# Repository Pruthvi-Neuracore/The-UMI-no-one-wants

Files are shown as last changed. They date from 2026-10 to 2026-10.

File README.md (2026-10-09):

# The UMI no one wants

<p align="center">
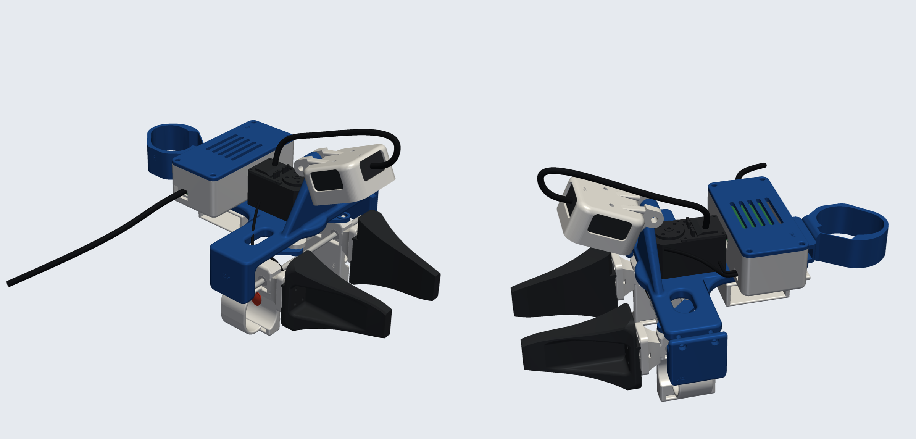
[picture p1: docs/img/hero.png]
The UMI no one wants: hand-worn gripper with an Intel RealSense D405 wrist camera
  
</p>

A hand-worn gripper for collecting bimanual manipulation data without a robot in the loop. It has an
**Intel RealSense D405** depth camera on the wrist, an on-board **IMU and Raspberry Pi Pico 2**, a **record button** under
your index finger, and a single USB cable to your laptop.

- **Depth wrist camera:** the D405 sits in a cup on a stiff Ø12 / M4 hinge at the end of a braced camera post that flares
  out of the frame; triangulated gussets tie both hinge lugs into the cup. It looks forward and down at the fingers (65° below horizontal, about 9–10 cm away; the D405's minimum
  range is 7 cm). The camera cable leaves from the top window and runs back into the electronics box.
- **Finger sleeves:** each finger link has a sleeve that wraps the finger, so the fingers stay in place while you open and
  close the gripper.
- **Record button:** a 6 × 6 mm tactile switch sits in the inner wall of the index-finger sleeve under a soft, domed
  TPU pad where your finger pad rests. Press it with your index finger, once to start recording and again to stop. It's wired to the Pico.
- **One cable:** a closed electronics box holds a USB 3 hub, the Pico 2 and the IMU. The camera and the Pico both connect to
  the hub, and one USB-C cable goes to the laptop. See [docs/electronics.md](docs/electronics.md).
- **Universal tip flange:** each finger link has a 20 × 30 mm flange with M2 (8 × 12), M3 (12 × 24 + centre pair) and M4
  (12 mm pair) hole patterns, so you can bolt on tips that match different robot grippers.
- **Moulded look:** every printed part is softly rounded: a blended T-plate outline, rounded slot rims, a concave blend into
  the end wall; the end cover and electronics box match.
- **Small PG mark:** every printed part has a small PG logo engraved 0.2 mm deep on one visible face, as a subtle
  maker's mark. The gripper tips stay plain.
- **Checked in a full assembly:** the gripper is clash-checked closed, half-open and fully open with every tip set.

## Record button

<p align="center">
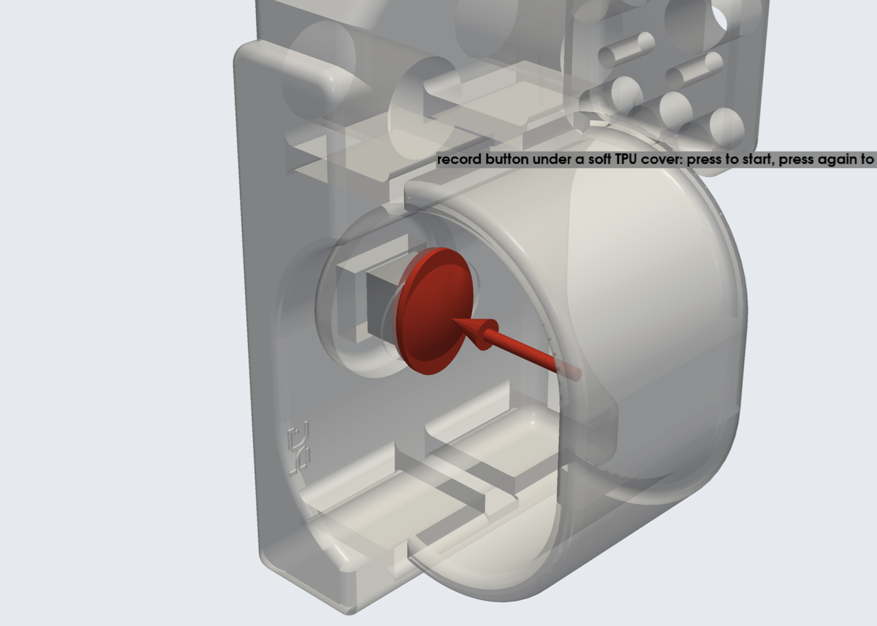
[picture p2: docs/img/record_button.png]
Record button at the front of the index-finger sleeve
  
</p>

A 6 × 6 mm tactile switch is set into the inner wall of the index-finger sleeve, where the finger pad rests, under a soft
TPU cover: a 12 × 9 mm oval pad with a gentle 0.8 mm dome and rounded rim, so nothing sharp touches your finger, and a nub
underneath that presses the switch. The cover sits in a matching oval recess, and a rounded boss on the outside of the paddle
gives the switch its depth. A cavity behind the switch leaves room for its legs and solder joints and opens at the back
for soldering. Press it with your index finger: **press once to start recording, press again to stop.** It's wired to the Pico (GP15 to ground,
internal pull-up), so the recording software only has to watch one input; see [docs/electronics.md](docs/electronics.md).
That wall is also the one your finger pushes to close the gripper, so use a stiff switch (about 250–320 gf); the
software can tell a deliberate press from a grasp by its duration. The wires leave through the back of the paddle and
run along the frame to the electronics box with a little slack for the finger link's travel.

## Tips for different robots

Swap the tips to match the robot you'll deploy on, so the jaws on the device have the same shape as the robot's fingers.

| Tips on the device | Robot |
|---|---|
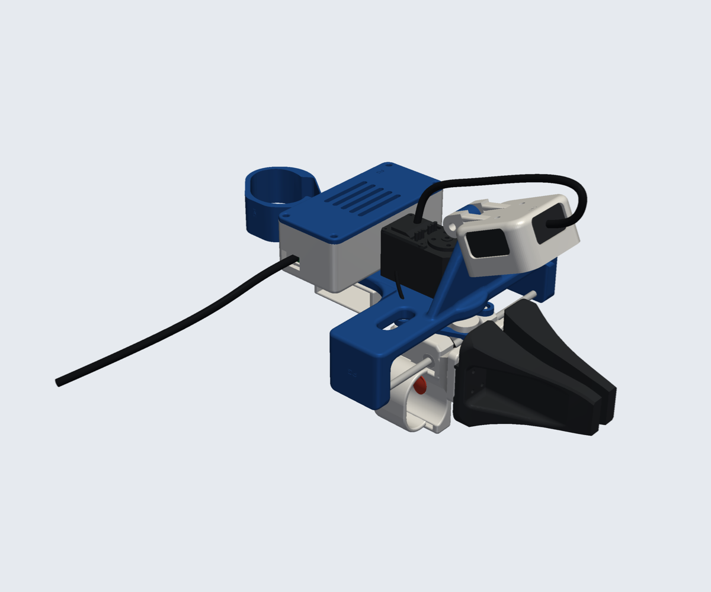
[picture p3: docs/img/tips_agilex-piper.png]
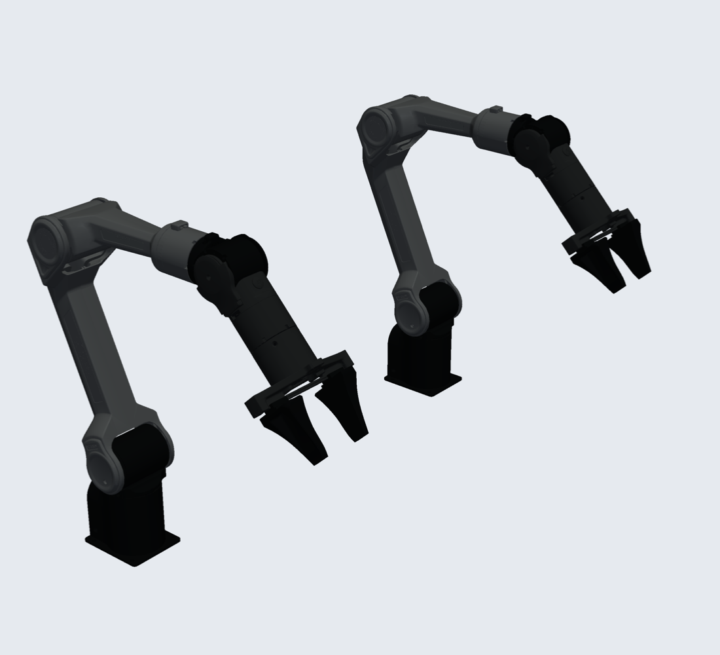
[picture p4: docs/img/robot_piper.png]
|  **AgileX Piper tips** |  **AgileX Piper** |
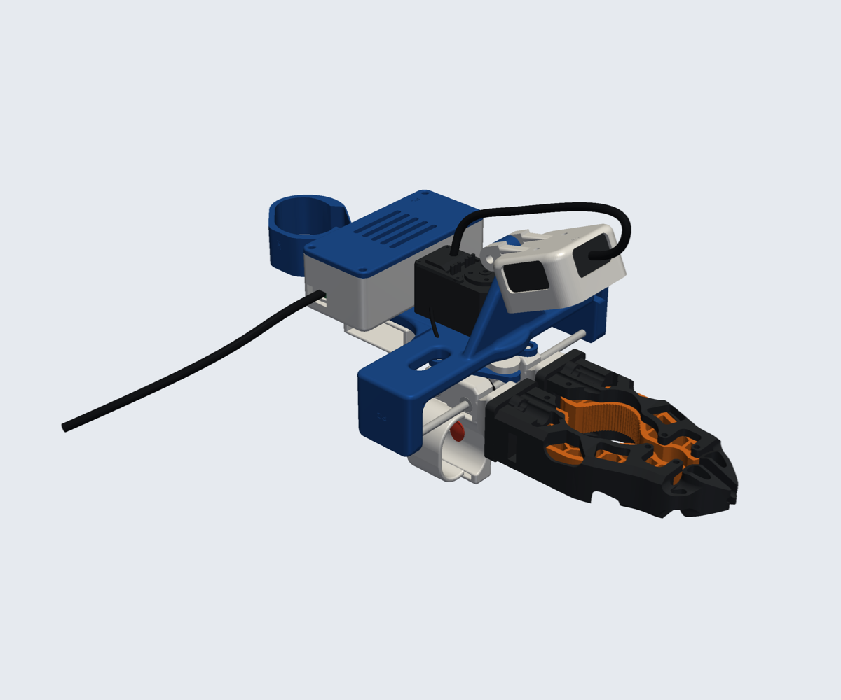
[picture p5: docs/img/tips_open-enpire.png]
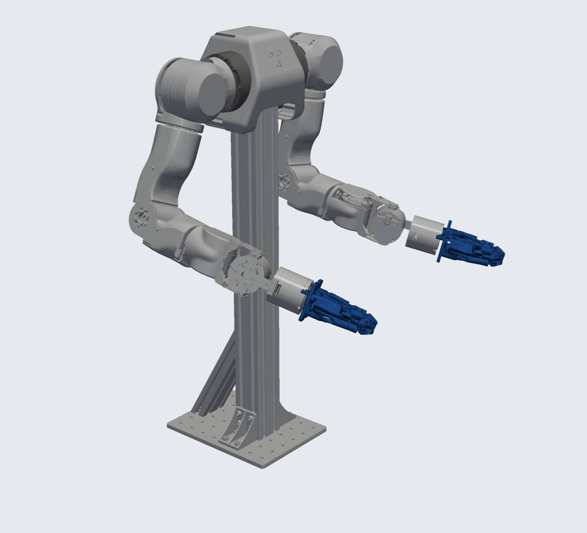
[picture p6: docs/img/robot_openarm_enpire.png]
|  **Open-ENPIRE compliant fingers** |  **OpenArm with Open-ENPIRE fingers** |
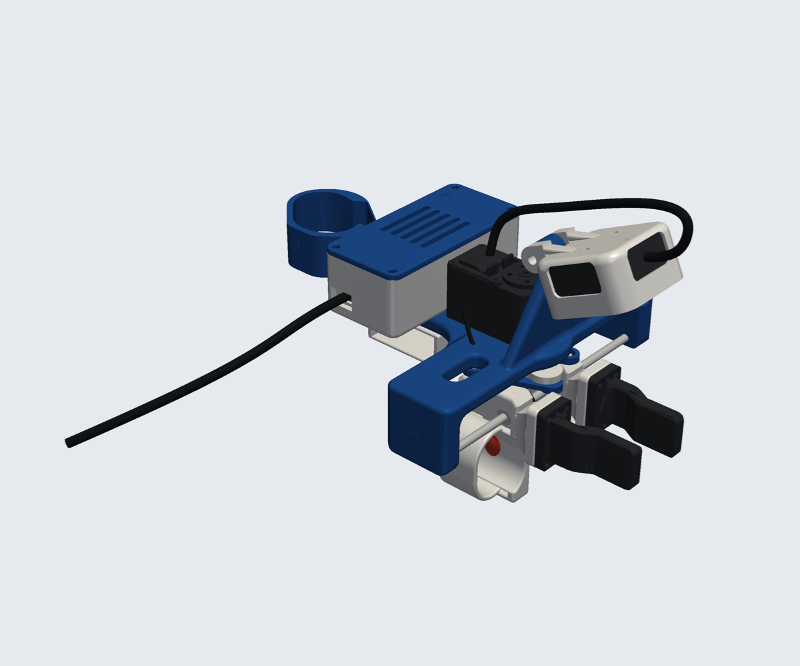
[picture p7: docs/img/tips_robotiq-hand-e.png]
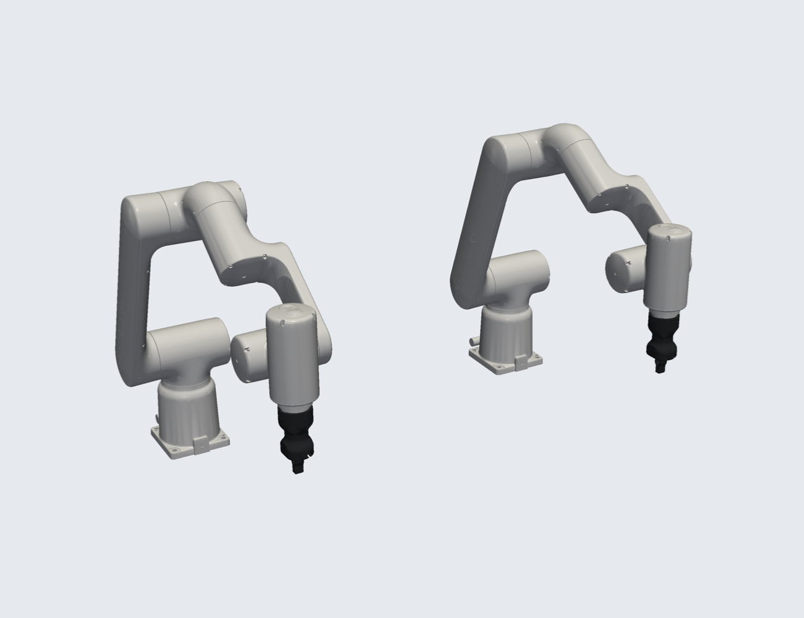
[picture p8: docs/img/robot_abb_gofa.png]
|  **Robotiq Hand-E fingers** |  **ABB GoFa CRB 15000 (dual) with Hand-E** |
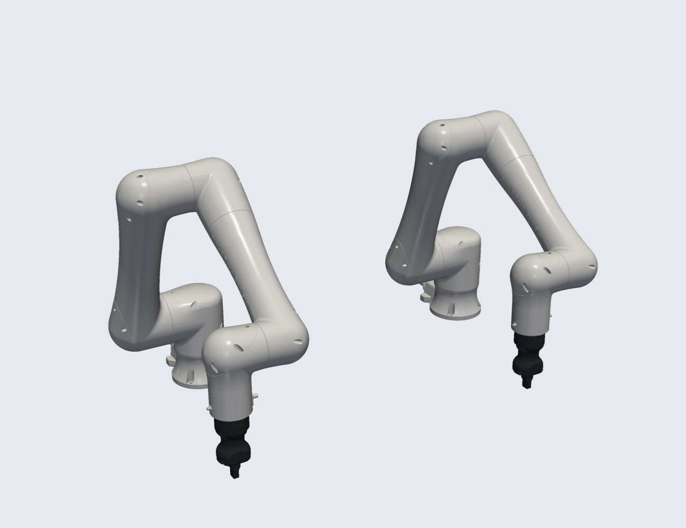
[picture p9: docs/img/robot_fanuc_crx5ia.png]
|  **Robotiq Hand-E fingers** |  **FANUC CRX-5iA (dual) with Hand-E** |
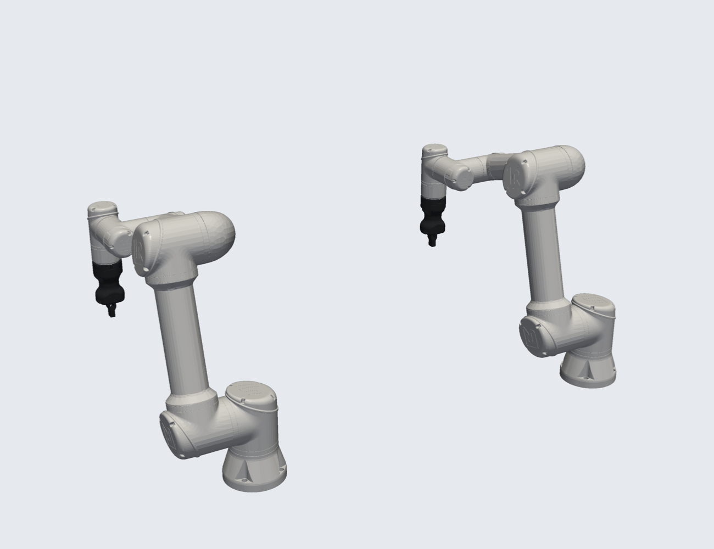
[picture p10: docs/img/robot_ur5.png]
|  **Robotiq Hand-E fingers** |  **UR5 (dual) with Hand-E** |

- **Piper tips** (`hardware/STL/gripper_tips/AgileX-Piper/`): the AgileX Piper jaw and pad, shown on the device above.
- **Open-ENPIRE tips, for OpenArm** (`hardware/STL/gripper_tips/Open-ENPIRE/`): the compliant finger from
  [Open-ENPIRE-Gripper](https://github.com/pgeedh/Open-ENPIRE-Gripper) with its robot mount replaced by a flange plate
 . The matching OpenArm finger is in `Open-ENPIRE/robot/OpenArm_Hard.stl` (mm), so the same finger
  shape is on the device and on the robot. The ENPIRE fingers are about 32 mm thick, so the jaws meet a little before
  the mechanism's own stop.
- **Hand-E tips, for ABB, FANUC and UR** (`hardware/STL/gripper_tips/Robotiq-Hand-E/`): the actual Robotiq Hand-E finger
  on a flange plate. Print it twice; the index jaw is the same part turned 180°, so the stepped
  fingertips face each other.

Robot renders are made from the robots' published descriptions (sources in
[`hardware/NOTICE.md`](hardware/NOTICE.md)).

## Assembly

The full assembled device (right hand, half open) is in [`assembly/`](assembly/), once per tip set:

| File | Use |
|---|---|
| `umi_right_agilex-piper.glb`, `umi_right_open-enpire.glb`, `umi_right_robotiq-hand-e.glb` | Coloured, one node per part, metres, Y up; drag into Onshape, Blender or any glTF viewer |
| `umi_right_agilex-piper.stl`, `umi_right_open-enpire.stl`, `umi_right_robotiq-hand-e.stl` | One merged mesh in mm, Z up |

The left hand is the mirror image.

## Parts

<p align="center">
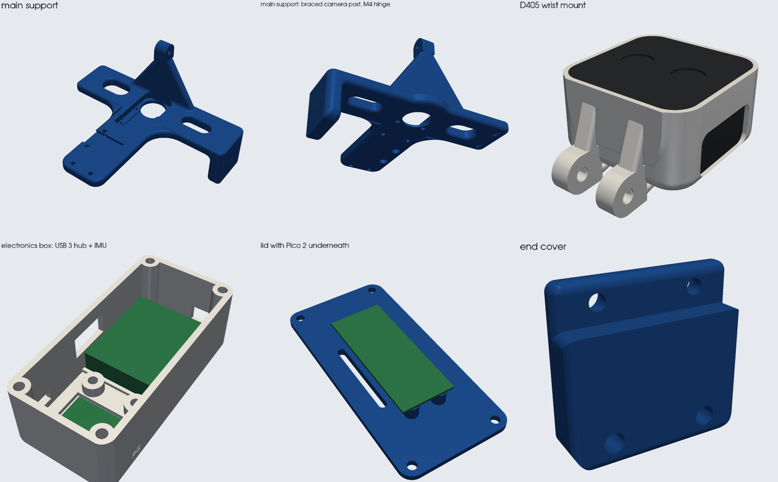
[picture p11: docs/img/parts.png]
Main support, D405 wrist mount, electronics box and lid, end cover
  
</p>

Print everything in `hardware/STL/right/` for a right hand or `hardware/STL/left/` for a left hand, plus a pair of
tips from `hardware/STL/gripper_tips/`. STEP files for every part are in `hardware/STEP/`.

| Part | File |
|---|---|
| Main support (T-plate with camera post) | `main_support.stl` |
| End cover | `end_cover.stl` |
| D405 wrist mount (cup on the M4 hinge) | `d405_wrist_mount.stl` |
| Record-button cover (TPU) | `button_cover_tpu.stl` |
| Electronics box + lid | `electronics_box.stl`, `electronics_lid.stl` |
| Thumb and index/middle finger links (finger sleeve, universal tip flange; record button in the index sleeve) | `*_thumb_link.stl`, `*_index_middle_finger_link.stl` |
| Crank, connecting links, hand support base, controller support | `crank_mechanism_plate.stl`, `connecting_link_1/2.stl`, `hand_support_base.stl`, `*_controller_support.stl` |

### Tip flange hole patterns

| Screws | Pattern | Fixing |
|---|---|---|
| 4× M2 | 8 × 12 mm | Self-tapping (fits every tip in `gripper_tips/`) |
| 6× M3 | 12 × 24 mm rectangle + centre pair at ±12 mm | M3 heat-set inserts (Ø4.0 × 5) |
| 2× M4 | 12 mm apart, centred | M4 heat-set inserts (Ø5.6 × 7) |

## Hardware

Everything to buy is in [docs/bom.md](docs/bom.md). Notes:

- **Camera:** Intel RealSense D405. Fix it with 2× M3×5 screws into its rear holes (2× M3×0.5, 20 mm apart, 4 mm max thread depth).
- **Camera hinge:** 1× M4×30 bolt with a nyloc nut.
- **Record button:** 1× 6 × 6 mm tactile switch (stiff, ~250–320 gf), ~30 cm of thin, flexible 2-core wire, and the
  `button_cover_tpu.stl` cover printed in TPU 95A.
- **Electronics:** Raspberry Pi Pico 2, a BNO085 IMU, a small USB 3 hub and short cables. No separate servo controller or power supply. Full list and wiring: [docs/electronics.md](docs/electronics.md).

## Files

| Path | What |
|---|---|
| `hardware/STL` | Printable parts: `right/`, `left/` and `gripper_tips/` |
| `hardware/STEP` | The same parts as STEP, for editing in CAD |
| `assembly/` | Full assembly as GLB and STL |
| `docs/bom.md` | Bill of materials |
| `docs/electronics.md` | Electronics, wiring and power |

## Strength

Every printed part was analysed with linear-elastic FEA in PLA (E = 3 GPa), with quadratic tetrahedra
meshed from the STEP files and checked against hand calculations. Load cases are 15 g knocks on the camera, a 30 N
grip with the tip's 70 mm lever, a 40 N finger press, and hand and VR-controller loads. Safety factors are against
30 MPa (along layers) and 15 MPa (across layers). Results are in [`docs/fea_results.csv`](docs/fea_results.csv), with stress maps in `docs/img/fea/`.

| Part | Load case | Safety factor (along / across layers) |
|---|---|---|
| Main support | camera knock, 15 g (vertical / sideways / fore-aft) | 29 / 14, 20 / 10, 17 / 8 |
| Main support | grip push on the rods, 2 × 30 N, end wall only (conservative) | 3.4 / 1.7 |
| Finger link | 30 N grip on the tip, 70 mm lever | 5.5 / 2.7 |
| Crank plate | 30 N on each crank pin | 52 / 26 |
| Connecting link | 40 N pull | 65 / 32 |

The D405 mount, end cover, electronics box and lid, hand support base and controller support haven't been analysed yet.

## Grip force

The device records jaw opening (the servo's encoder), IMU motion and the depth camera. It does **not** measure grip
force yet: the servo only runs as an encoder with its torque off, so its load reading isn't meaningful. Thin-film force
sensors under the tips, read by the Pico's analog inputs, are the planned way to add it.

## References

UMI pioneered in-the-wild data collection without a robot in the loop, and YUBI brought that idea to a finger-driven
V-shaped gripper. Generalist built a proprietary hand-worn device for a V-shaped gripper too. This project is an
open-source hand-worn device for robot arms with parallel-jaw grippers.

- Cheng Chi, Zhenjia Xu, Chuer Pan, Eric Cousineau, Benjamin Burchfiel, Siyuan Feng, Russ Tedrake, and Shuran Song.
  "Universal Manipulation Interface: In-The-Wild Robot Teaching Without In-The-Wild Robots." *Robotics: Science and
  Systems (RSS)*, 2024. https://umi-gripper.github.io/
- Takehiko Ohkawa, Jumpei Arima, Yuki Noguchi, et al. "YUBI: Yielding Universal Bidigital Interface for Bimanual
  Dexterous Manipulation at Scale." arXiv:2606.10244, 2026. https://yubi.airoa.io/

## License

Third-party sources, licenses and the list of modifications are in [`hardware/NOTICE.md`](hardware/NOTICE.md).

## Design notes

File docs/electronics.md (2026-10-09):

# Electronics: one USB cable

Everything on the device goes through a small USB 3 hub inside the electronics box, so one USB-C cable runs to the laptop.

```
 D405 depth camera ──USB 3──┐
                            ├── USB 3 hub (in the box) ══ one USB-C cable ══ laptop
 Raspberry Pi Pico 2 ──USB──┘
   ├── I2C ── IMU (BNO085-class, in the box floor, rigid to the frame)
   ├── GPIO ── record button (index sleeve: press to start, press again to stop)
   └── UART (half-duplex) ── STS3215 servo bus (gripper width encoder)
```

The Pico can't relay the camera: its USB port is full-speed (12 Mbit/s), and the D405 needs USB 3 for depth plus colour
(USB 2 at 480 Mbit/s only with reduced modes). So the camera goes straight to the hub, and the Pico streams the
IMU and gripper-width data. Both arrive on the laptop over the same cable and are synchronised there by timestamp.

## Parts

| Part | Notes |
|---|---|
| Raspberry Pi Pico 2 | On four M2 standoffs under the box lid (holes 47 × 11.4 mm) |
| BNO085 IMU breakout | In the box floor pocket (28 × 24 mm). **Check your board's outline**; secure it with double-sided tape or epoxy so it can't move |
| USB 3 hub board, USB-C upstream | Bay is 38 × 42 mm, up to ~14 mm tall (VL817-type 4-port boards). **Check your board's size** before printing |
| Short cables | D405 USB-C to USB-A (~15 cm, USB 3), Pico micro-USB to USB-A (~10 cm, right-angle helps) |
| 6 × 6 mm tactile switch, stiff (~250–320 gf) | Record start / stop. In the inner wall of the index sleeve under the domed TPU cover; legs and solder joints sit in the cavity behind it |
| 2-core wire, ~30 cm, flexible | Button to the Pico, with slack for the index link's travel |
| 74LVC1G125 or 1 kΩ resistor | Joins Pico TX/RX onto the servo's single-wire bus |
| 2× M3×8 + 2 M3 heat-set inserts | Box to arm, from the hand side (counterbored, heads sit flush) |
| 4× M3×6 + 4 M3 heat-set inserts | Lid to box |
| 4× M2×4 self-tapping screws | Pico to the lid standoffs |

## Wiring

| From | To |
|---|---|
| IMU SDA / SCL | Pico GP4 / GP5 (I2C0) |
| IMU VIN / GND | Pico 3V3(OUT) / GND |
| Servo bus data | Pico GP0 (TX) through the buffer or 1 kΩ, and GP1 (RX) direct |
| Servo V+ / GND | Hub 5 V / GND. The servo is only read as an encoder (torque off), so 5 V is enough |
| Record button | Pico GP15 and GND (use the internal pull-up; pressed = low) |
| Pico USB | Hub downstream port |
| D405 USB | Hub downstream port (USB 3) |

## Power

Everything runs from the laptop port. A USB 3 port gives 900 mA, which covers the D405, the Pico, the IMU and an idle
servo. If the camera drops out, use a USB-C port that supplies more current, or a powered hub.

## Box openings

- **Camera side:** a slot for the D405 cable (the plug passes through) and a slot shared by the servo and button cables.
- **Side wall:** the hub's USB-C upstream port.
- **Lid:** vent slots.

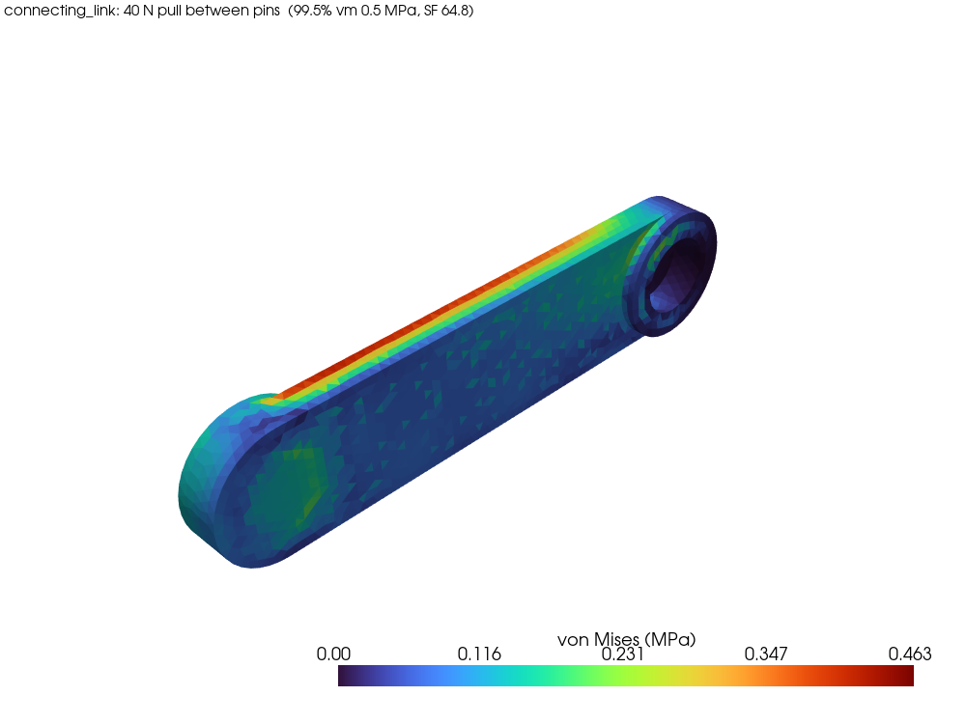
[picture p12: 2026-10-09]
docs/img/fea/connecting_link_0.png

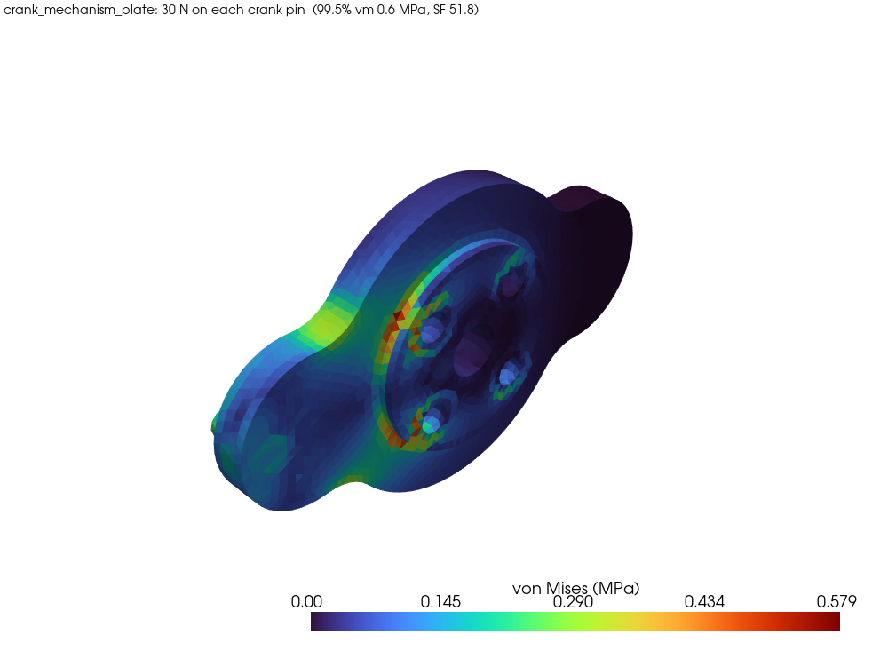
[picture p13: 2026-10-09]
docs/img/fea/crank_mechanism_plate_0.png

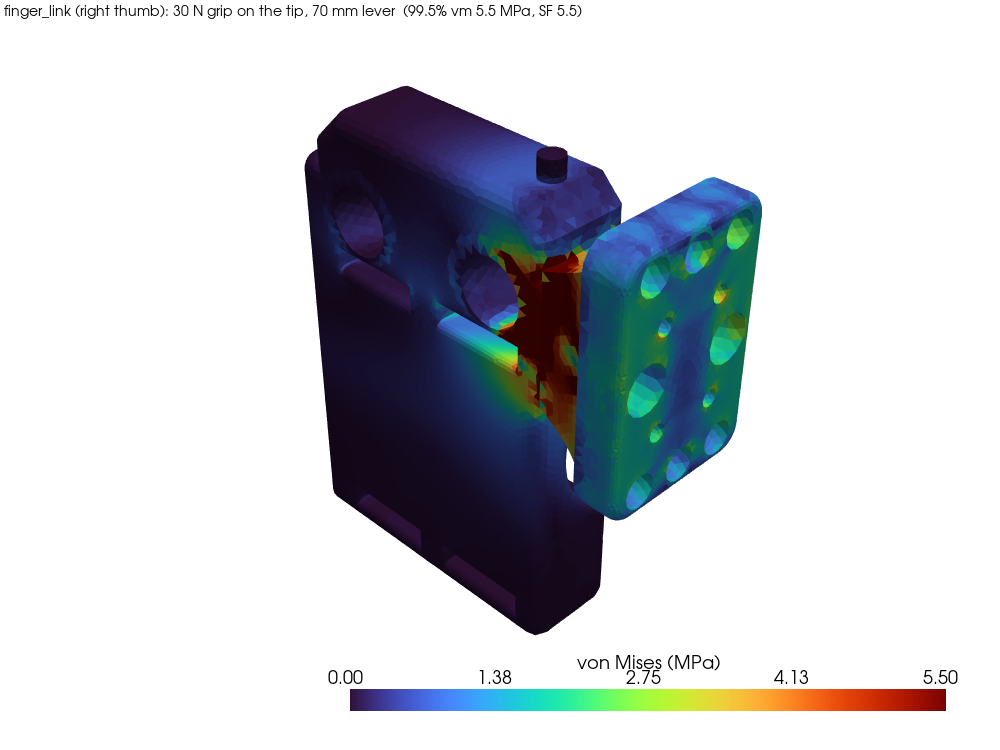
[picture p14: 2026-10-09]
docs/img/fea/finger_link_0.png

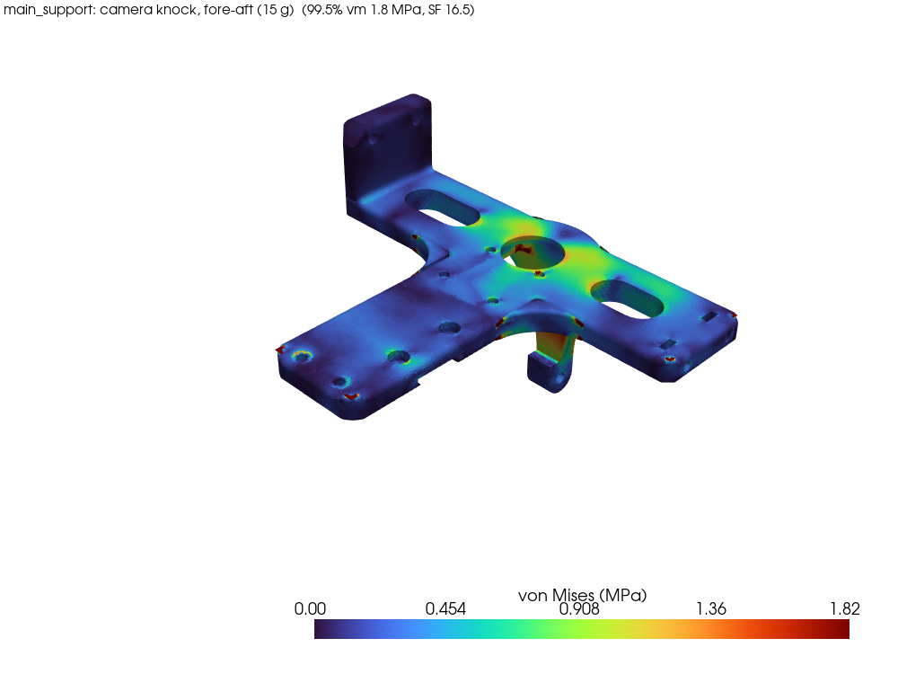
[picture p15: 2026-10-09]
docs/img/fea/main_support_2.png

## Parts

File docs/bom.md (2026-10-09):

# Bill of materials

Quantities are for a **pair** (one right-hand and one left-hand device).

## Printed parts

| Part | Material | Qty |
|---|---|---|
| Everything in `hardware/STL/right/` and `hardware/STL/left/` except the button cover | PLA or PETG, ~200 g per device | 1 set each |
| `button_cover_tpu.stl` | TPU 95A | 2 |
| Tips from `hardware/STL/gripper_tips/` (Piper, Open-ENPIRE or Hand-E) | PLA / PETG (ENPIRE soft inserts in TPU) | 2 pairs |

## Mechanics

| Part | Qty |
|---|---|
| MR63ZZ bearing, 3 × 6 × 2.5 mm | 8 |
| LM4UU linear bearing, 4 × 8 × 12 mm | 8 |
| Ø4 mm × 135 mm stainless rod | 4 |
| Feetech STS3215 servo (used as the jaw-width encoder, torque off) | 2 |
| M4×30 bolt + nyloc nut (camera hinge) | 2 |
| M3×5 screws (D405 to its cup) | 4 |
| M3 screws: 4× M3×20, 8× M3×12, 8× M3×15 (mechanism); 4× M3×8 (box to arm); 8× M3×6 (lid) | 32 |
| M3 heat-set inserts, Ø4.0 × 5 (box, lid, M3 tip pattern) | ~24 |
| M2 screws + nuts (mechanism, tips, Pico) | ~40 |
| Hook-and-loop straps, 15 cm | 8 |

## Electronics

| Part | Qty |
|---|---|
| Intel RealSense D405 | 2 |
| Raspberry Pi Pico 2 | 2 |
| BNO085 IMU breakout | 2 |
| USB 3 hub board, USB-C upstream (fits a 38 × 42 × 14 mm bay) | 2 |
| 6 × 6 mm tactile switch, stiff (~250–320 gf) | 2 |
| Short USB cables (D405 to hub, Pico to hub) and one USB-C cable to the laptop per device | 2 sets |
| 74LVC1G125 buffer or 1 kΩ resistor (servo bus) | 2 |
| Thin 2-core wire, ~30 cm | 2 |

Wiring and power are in [electronics.md](electronics.md).

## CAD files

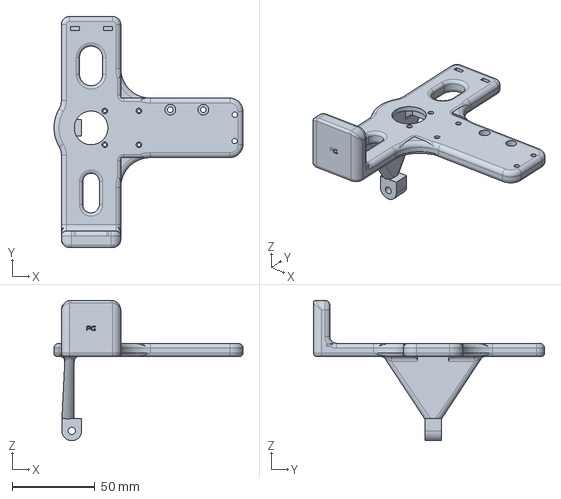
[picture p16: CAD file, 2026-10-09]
hardware/STEP/right/main_support.step
114.5 x 140.0 x 85.0 mm

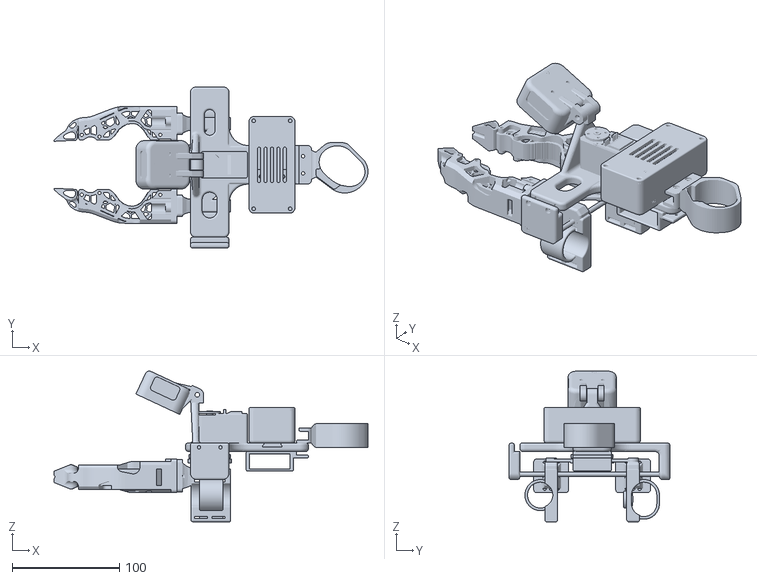
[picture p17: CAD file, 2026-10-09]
assembly/umi_right_open-enpire.stl
292.6 x 150.0 x 140.6

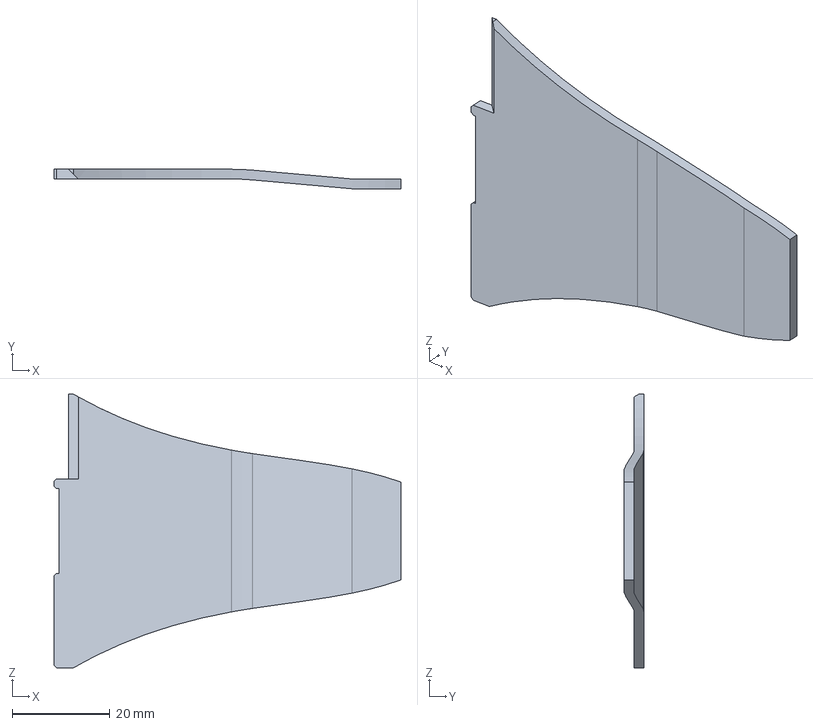
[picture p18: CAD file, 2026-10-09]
hardware/STEP/gripper_tips/AgileX-Piper/Piper-LEFT-Gripper-Pad.step
71.0 x 4.00 x 56.0 mm

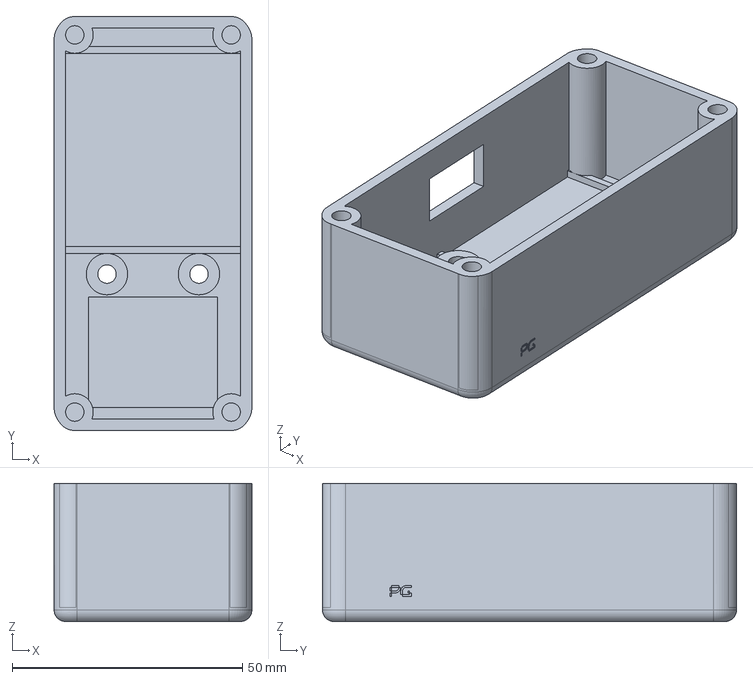
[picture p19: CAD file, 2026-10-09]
hardware/STEP/left/electronics_box.step
43.0 x 90.0 x 30.0 mm

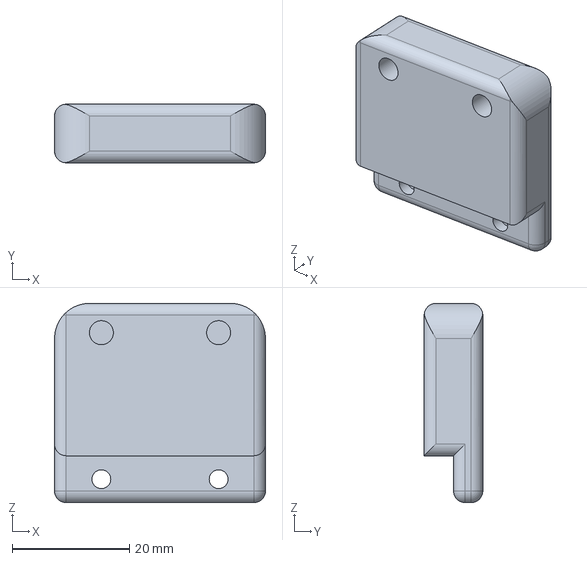
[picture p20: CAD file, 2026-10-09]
hardware/STEP/right/end_cover.step
36.0 x 10.0 x 34.0 mm

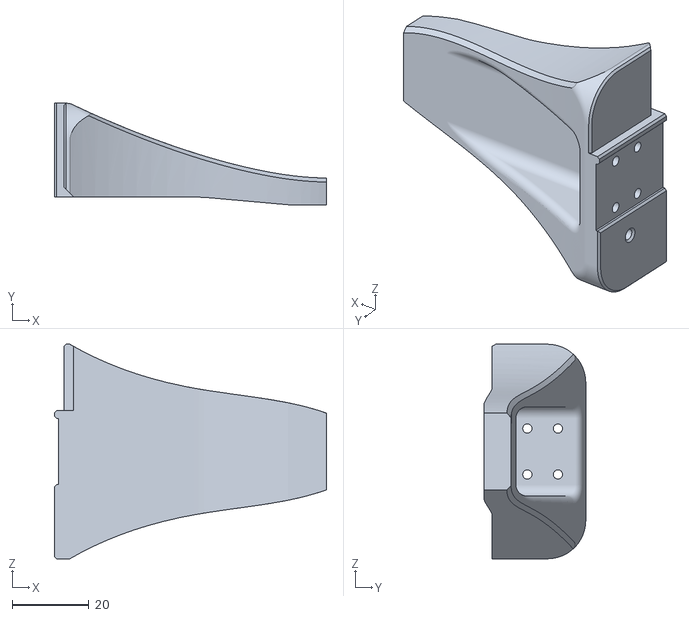
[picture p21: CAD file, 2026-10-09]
hardware/STL/gripper_tips/AgileX-Piper/Agile-X-Piper-LEFT-Gripper.stl
71.0 x 26.5 x 56.0

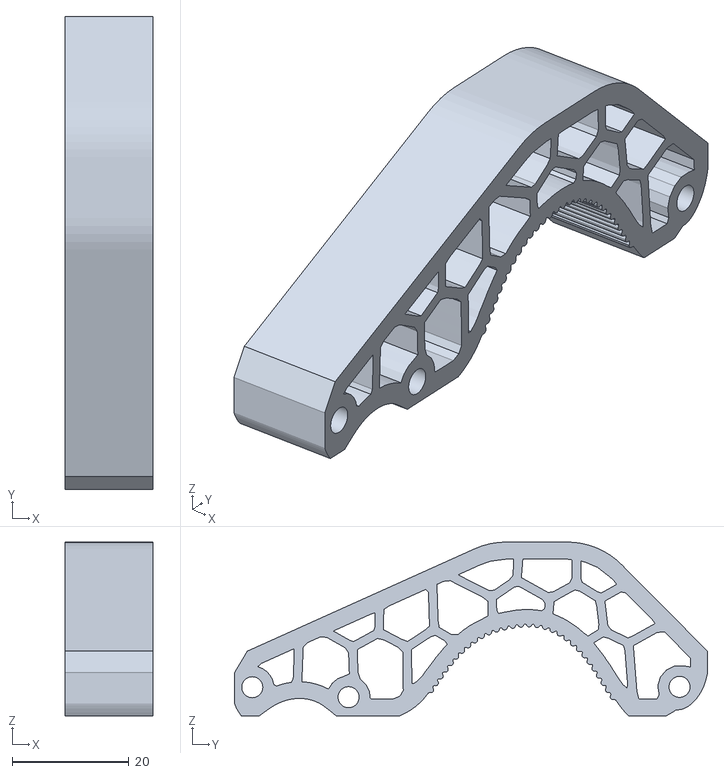
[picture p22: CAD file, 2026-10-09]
hardware/STL/gripper_tips/Open-ENPIRE/ENPIRE-RIGHT-Soft-Insert.stl
15.0 x 81.0 x 29.8

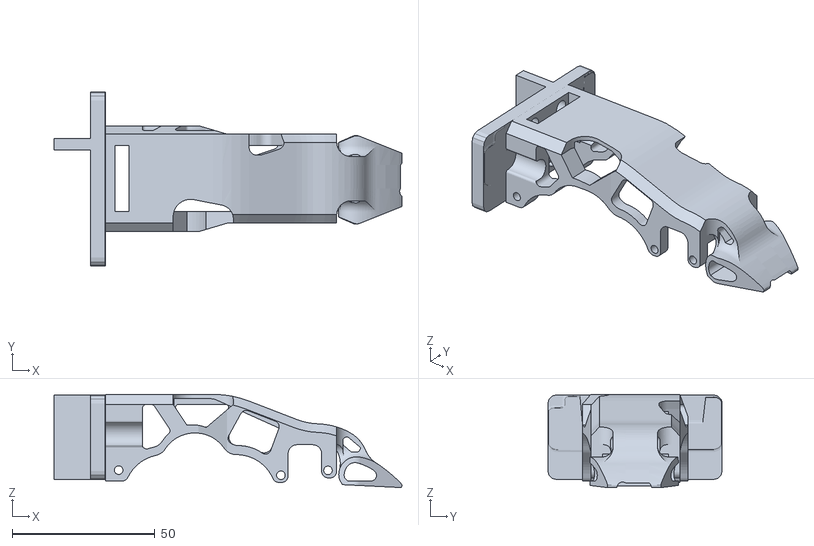
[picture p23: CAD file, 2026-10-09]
hardware/STL/gripper_tips/Open-ENPIRE/robot/OpenArm_Hard.stl
121.7 x 61.0 x 32.6

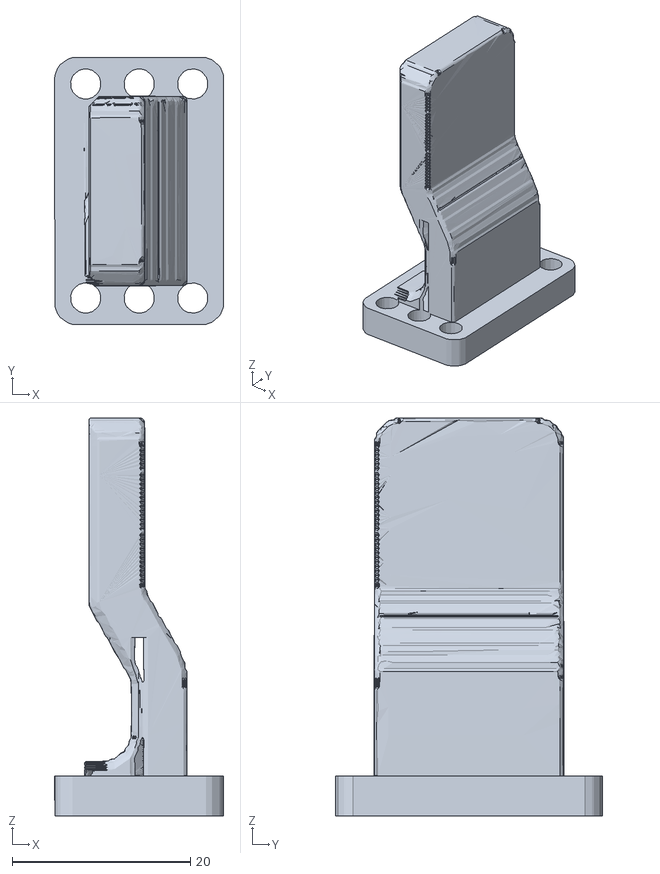
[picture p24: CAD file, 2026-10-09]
hardware/STL/gripper_tips/Robotiq-Hand-E/Hand-E-Finger.stl
19.0 x 29.9 x 44.6

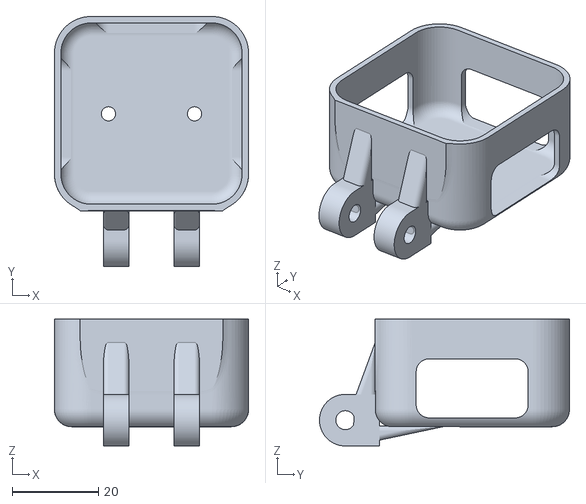
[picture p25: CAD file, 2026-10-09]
hardware/STL/left/d405_wrist_mount.stl
45.1 x 58.1 x 29.5

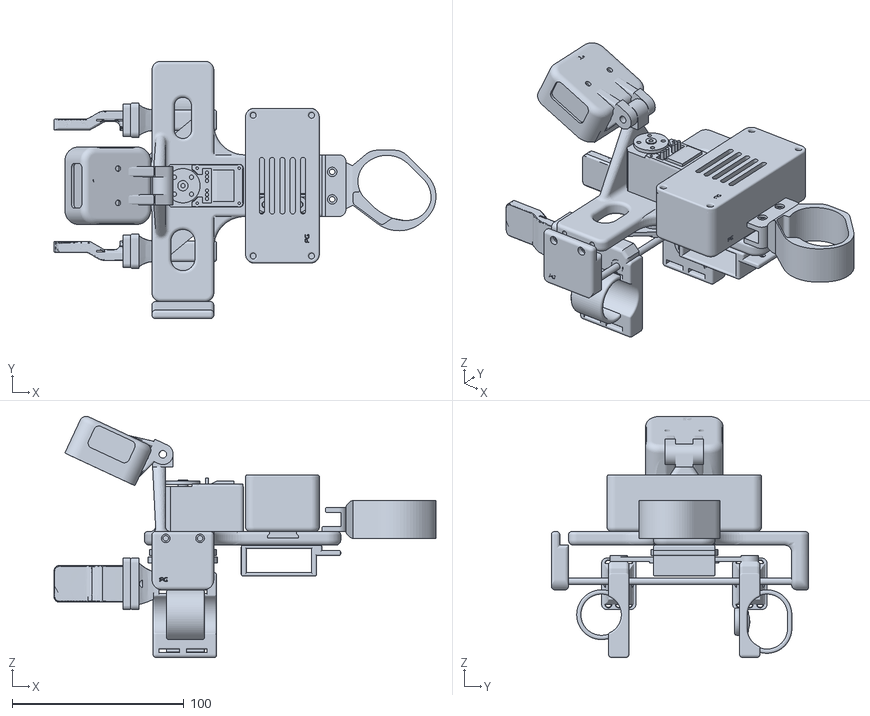
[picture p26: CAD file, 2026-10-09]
assembly/umi_right_robotiq-hand-e.stl
222.6 x 150.0 x 140.6

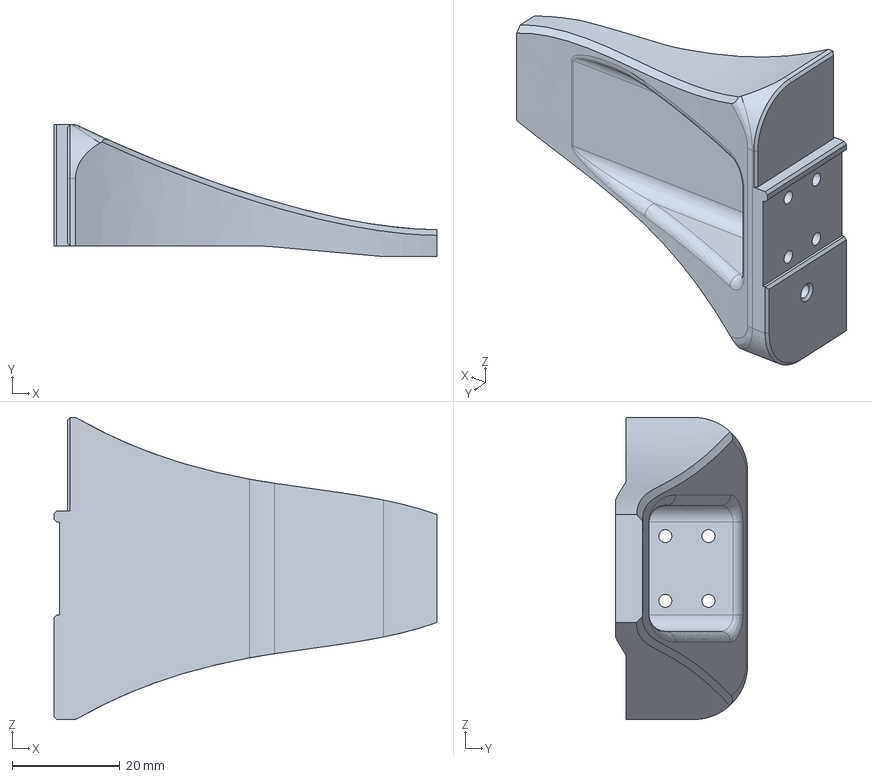
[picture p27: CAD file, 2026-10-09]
hardware/STEP/gripper_tips/AgileX-Piper/Piper-LEFT-Gripper-Jaw.step
71.0 x 24.5 x 56.0 mm

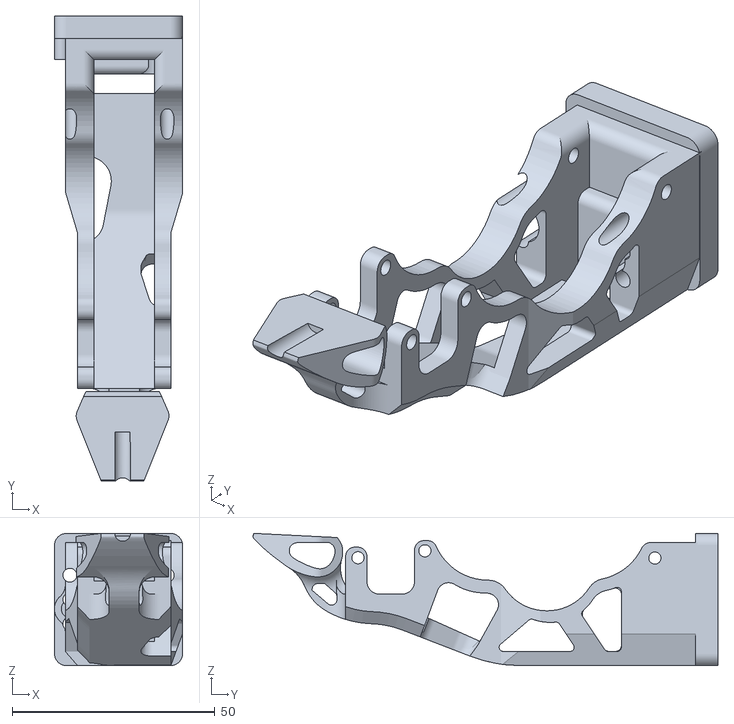
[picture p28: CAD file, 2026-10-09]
hardware/STL/gripper_tips/Open-ENPIRE/ENPIRE-LEFT-Jaw.stl
31.6 x 114.6 x 32.6

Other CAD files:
hardware/STEP/left/main_support.step
hardware/STEP/left/end_cover.step
hardware/STEP/right/electronics_box.step
hardware/STL/gripper_tips/AgileX-Piper/Agile-X-Piper-RIGHT-Gripper.stl
assembly/umi_right_agilex-piper.stl
hardware/STEP/gripper_tips/AgileX-Piper/Piper-RIGHT-Gripper-Jaw.step
hardware/STEP/gripper_tips/AgileX-Piper/Piper-RIGHT-Gripper-Pad.step
hardware/STEP/left/button_cover_tpu.step
hardware/STEP/left/connecting_link_1.step
hardware/STEP/left/connecting_link_2.step
hardware/STEP/left/crank_mechanism_plate.step
hardware/STEP/left/electronics_lid.step
hardware/STEP/left/hand_support_base.step
hardware/STEP/left/left_controller_support.step
hardware/STEP/left/left_index_middle_finger_link.step
hardware/STEP/left/left_thumb_link.step
hardware/STEP/right/button_cover_tpu.step
hardware/STEP/right/connecting_link_1.step
hardware/STEP/right/connecting_link_2.step
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

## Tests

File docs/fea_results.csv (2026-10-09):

part | case | von_mises_p99.5_MPa | max_disp_mm | SF_along_layers | SF_across_layers
crank_mechanism_plate | 30 N on each crank pin | 0.58 | 0.005 | 51.8 | 25.9
connecting_link | 40 N pull between pins | 0.46 | 0.034 | 64.8 | 32.4
main_support | camera knock vertical (15 g) | 1.05 |  | 28.7 | 14.3
main_support | camera knock sideways (15 g) | 1.53 |  | 19.7 | 9.8
main_support | camera knock fore-aft (15 g) | 1.82 |  | 16.5 | 8.2
main_support | grip push on rods 2 x 30 N at the end wall only (conservative; the end cover shares it in practice) | 8.89 | 0.914 | 3.4 | 1.7
finger_link (right thumb) | 30 N grip on the tip | 70 mm lever | 5.50 | 0.071 | 5.5 | 2.7

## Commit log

2026-10-09 Add v0.1 parametric CAD: shared rack-and-pinion jaw module, hand-worn collector, OpenArm unit, camera dock
    - build123d source in cad/src/umi with stroke and assembly interference checks
    - HandUMI tip interface kept; HandUMI tips and YUBI OpenArm flange vendored unmodified
    - Pico + BNO085 + AS5600 pod on the collector, STS3215 cradle on the OpenArm unit
    - IMX335 and Intel D405 camera adapters sharing one viewpoint
    - design notes, must-verify list and BOM in docs/design.md
    [cam_d405_cradle.step, cam_d405_cradle.stl, cam_imx335_mount.step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]
2026-10-09 Add named, coloured assembly exports (STEP, GLB, glTF) for the collector and OpenArm unit
    [collector_closed.step, collector_open.step, openarm_unit_closed.step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]
2026-10-09 Switch to HandUMI hardware with an Intel RealSense D405 camera mount
    - import HandUMI hardware and BOM unmodified (Apache-2.0, fc7462a)
    - add d405_camera_mount: HandUMI hinge kept exactly, new plate for the D405 rear 2x M3 (20 mm) pattern
    - v0.1 rack-and-pinion design moved to branch v0.1-rack-pinion
    [ARX-X5-2023-LEFT-Gripper.step, ARX-X5-2023-LEFT-Gripper.stl, ARX-X5-2023-RIGHT-Gripper.step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]
2026-10-09 Adapt the supplied D405 wrist mount to the HandUMI camera hinge
    - remove the 4x M3 tab, fuse HandUMI's camera_mount knuckles to the cup edge
    - re-orient the cup into HandUMI's camera frame (tilt now set on the hinge)
    - full-part renders in the README; flat plate kept as an alternative
    [wrist_camera_mount.stl, wrist_d405_mount_handumi.step, wrist_d405_mount_handumi.stl]
2026-10-09 Add top cable window to the D405 wrist mount and HandUMI assembly reconstruction tools
    - wrist_d405_mount_handumi: cable window in the top wall matching the side windows
    - tools/assembly.py: places every HandUMI part from mating features, checks interference on B-rep solids, renders
    - tools/features.py, tools/occ.py helpers; STS3215 reference model (SO-ARM100, Apache-2.0)
    [STS3215_03a.step, wrist_d405_mount_handumi.stl]
2026-10-09 Redesign the T-plate, end cover and controller lid; full-assembly README render
    - redesign/restyle.py: blended T-plate with lightening slots, faceted ends and engraved name;
    matching end cover; vented controller lid. All mating features unchanged (verified by feature diff)
    - tools/assembly.py: uses the redesign, adds the servo-controller box; no interference at closed, half and open
    - README in HandUMI style with the full assembly render and only the latest D405 mount
    [controller_lid.step, controller_lid.stl, end_cover.step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]
2026-10-09 Stiffer camera joint, camera aimed at the fingertips, orange/blue look
    - main_support: tapered camera post with a Ø12 / M4 hinge knuckle replaces the 3 x 15 mm strip
    - D405 wrist mount: Ø12 lugs on an M4 pivot (shared dimensions in redesign/hinge.py)
    - camera tilted 65 deg down toward the fingertips (89-104 mm away); clear of all parts from 40 to 80 deg
    - orange/blue renders; README shows only the new design; flat D405 plate removed
    [controller_lid.step, d405_camera_mount.step, d405_camera_mount.stl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]
2026-10-09 Flat part folders, rebuilt T-plate, universal tip flanges, PG logo, FEA (in progress)
    - hardware/{STL,STEP}/{right,left} now hold exactly the parts to print; redesign/ and d405/ part folders removed,
    original sources kept in redesign/source/
    - main_support rebuilt from one outline with uniform edge rounding; post flares into the plate; smaller slot by the end wall
    - finger links: lofted neck + 20 x 30 mm flange with M2 / M3 / M4 hole patterns for different gripper tips
    - PG logo replaces the text engraving; README drops HandUMI mentions
    - tools/fea.py: validated linear-elastic FEA; partial results in docs/fea_results.csv, stress maps in docs/img/fea
    [camera_mount.step, camera_mount.stl, connecting_link_1.step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]
2026-10-09 FEA: add finger-link result and summary table; remaining cases not run
    [fea_results.csv]
2026-10-09 Blend every surface: moulded T-plate, end wall, camera post, end cover and electronics box
    - T-plate rebuilt from an exact outline (no traced seams) with 3 mm top / 2 mm underside rounds, rounded slot rims,
    4 mm concave blend into a rebuilt end wall with 6 mm rounded corners, and a racetrack camera post blended into the plate
    - end cover and electronics box/lid rounded to match; all original holes and pockets still present; no interference
    [electronics_box.step, electronics_box.stl, electronics_lid.step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]
2026-10-09 Camera cradle, finger sleeves, record button, wires, tip gallery with robots, Open-ENPIRE tips, references
    - D405 cradle bolts rigidly under the frame (rounded column, 2x M3); camera aimed at the base of the gripper fingers
    - finger sleeves on all links; record button (12x12 tactile) at the front of the index sleeve, wired to Pico GP15
    - renders show the D405, servo, button and single USB-C cables
    - tip fitting for Piper, ARX X5, TRLC Dream, Trossen WidowX AI and Open-ENPIRE (adapted to the flange); robot renders
    - README: button close-up, tips-and-robots gallery, grip-force note, references (UMI, YUBI)
    [ENPIRE-LEFT-Jaw.stl, ENPIRE-LEFT-Soft-Insert.step, ENPIRE-LEFT-Soft-Insert.stl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]
2026-10-09 Hinged camera back, record button in the index sleeve wall, jaws from their source pairing, ENPIRE turned 90°
    - restore the blended camera post and Ø12 / M4 hinged D405 mount at 65° (camera cable leaves from the top window)
    - record button: 6x6 tactile switch flush in the inner wall of the index sleeve, backed by a boss; wires out the back
    - tips: both jaws share one rotation taken from their source left/right pairing (no swapped or upside-down jaws)
    - Open-ENPIRE fingers rotated 90° so the soft inserts face each other; flange holes re-laid to match
    - cable paths checked clear of all parts at closed, half and full open
    [ENPIRE-LEFT-Jaw.stl, ENPIRE-LEFT-Soft-Insert.step, ENPIRE-LEFT-Soft-Insert.stl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]
2026-10-09 Tips: swap the ARX X5 jaws between thumb and index; Dream gripper tips point inward (index jaw mirrored)
2026-10-09 README gallery: Piper, Robotiq Hand-E and OpenArm only; OpenArm rendered with Open-ENPIRE fingers
    [open-arm_enpire_left-jaw.stl]
2026-10-09 D405 mount: solid ridge under the cup fused to both hinge lugs (no thin neck); camera screws M3x10 through it
    [d405_wrist_mount.stl]
2026-10-09 Camera mount: triangulated gussets from both hinge lugs; record button: solder cavity and TPU soft-press cover
    [button_cover_tpu.step, button_cover_tpu.stl, d405_wrist_mount.stl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]
2026-10-09 Hand-E and Open-ENPIRE tips, dual-arm robot renders, assembly export, repo cleanup
    - Tips: Robotiq Hand-E finger on a flange plate and Open-ENPIRE jaws; robot-side ENPIRE fingers in mm; other tip sets removed
    - Robot renders: ABB GoFa CRB 15000, FANUC CRX-5iA and UR5 duals with Hand-E
    - assembly/: full right-hand assembly as GLB and STL for both tip sets
    - Small 0.2 mm PG mark engraved on every printed part
    - Ergonomic domed TPU button cover, round backing boss, solder cavity
    - Triangulated gussets on the D405 mount hinge lugs
    - All build code merged into cad/; old BOM replaced by docs/bom.md; README and NOTICE updated
    [ARX-X5-2023-LEFT-Gripper.step, ARX-X5-2023-LEFT-Gripper.stl, ARX-X5-2023-RIGHT-Gripper.step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]
2026-10-09 Bring back AgileX Piper tips (hero render) and Piper / OpenArm robot renders; Open-ENPIRE for OpenArm only
    - README gallery: Piper, OpenArm + Open-ENPIRE, then ABB GoFa / FANUC CRX-5iA / UR5 with Hand-E
    - assembly/: add the Piper-tip assembly
    - Open-ENPIRE robot-side fingers trimmed to the OpenArm one
    - cad/robots.py renders both robot sources
    [Agile-X-Piper-LEFT-Gripper.stl, Agile-X-Piper-RIGHT-Gripper.stl, I2RT-YAM_Hard.stl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]
2026-10-09 Keep main to downloads: STL/STEP parts, assembly, BOM and docs; build code moved to the cad branch
    [I2RT_UCG_Soft.stl, STS3215_03a.step, camera_mount.step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]
